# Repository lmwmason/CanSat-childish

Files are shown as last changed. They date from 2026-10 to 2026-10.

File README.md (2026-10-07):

# CanSat-childish







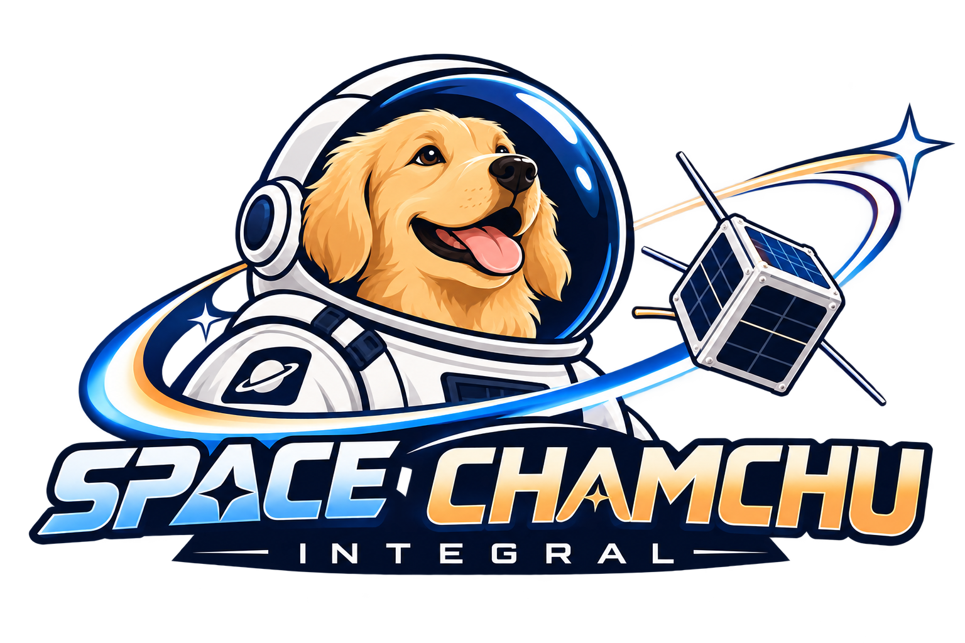
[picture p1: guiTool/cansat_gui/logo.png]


CanSat-childish is the open-source code and hardware for a two-tier CanSat
project by the Space Chamchu team: a **mother CanSat** that is dropped, steadies
itself with a reaction wheel, spins up, opens a door, ejects its wings and
glides back around the drop point, and small **child CanSats** that fall under a
parachute and record the descent. A **ground station** receives the mother's
telemetry over a TBS Crossfire link, shows it live and records it to CSV.

The repository holds every part of the system:

- **Mother firmware** — STM32F410RB. Fuses two IMUs, detects the drop, stabilizes
  and spins the body with a reaction wheel, opens the door, ejects the wings,
  flies the elevons (manual from the radio or automatic with GPS), detects the
  landing, and sends telemetry down the CRSF link.
- **Child firmware** — ATmega328 (Arduino Pro Mini). Reads barometer, IMU and
  humidity sensors, releases a parachute with a servo and logs the whole flight
  to EEPROM so it can be dumped over serial after landing.
- **Ground station** — a PyQt6 desktop app (Mission Planner style) that runs on a
  Raspberry Pi with a Crossfire Micro TX V2, or on a normal PC. Live flight view,
  ground track, CSV recording and the AUX switches of the mother.
- **Simulator** — the flight logic as a hardware-independent C core, run on a
  rigid-body physics engine, with a live 3D viewer.
- **PCB** — the KiCad project of the mother board.

## Mother mission

The mother's mission is a state machine on the STM32. Every number below is a
constant in the source and can be tuned.

1. **Drop detection** — the acceleration magnitude stays between 9.7 and
   9.9 m/s² for 300 ms **and** the AUX1 switch on the radio is on.
2. **2 s later** — the reaction wheel turns on and holds the current heading.
3. **Stable** (yaw rate under 8°/s and yaw error under 10° for 1 s) — the wheel
   spins the body up at full power.
4. **180°/s reached** — the servo opens the door.
5. **5 s at maximum speed**, then the wheel brakes and holds the heading again.
6. **Stable again** — the two wing servos eject the wings.
7. **Elevons** — the AUX2 switch selects manual (sticks) or automatic. Automatic
   mode levels the aircraft and circles around the point where the drop was
   detected (50 m radius) using the GPS.
8. **Landing** — motionless for 3 s (at least 10 s after the drop): the buzzer
   sounds and all LEDs blink.

## Tech stack

- **Mother firmware:** C, STM32 HAL, [STM32CubeMX](https://www.st.com/en/development-tools/stm32cubemx.html) project (`.ioc`) with IAR EWARM project files
- **Sensors on the mother:** MPU6050 + ICM-42688 (I2C), u-blox NEO-6M GPS (I2C / DDC), TBS Crossfire receiver (CRSF, UART)
- **Child firmware:** C++ / Arduino framework with [PlatformIO](https://platformio.org/); BMP280, MPU6050 (on-chip DMP), DHT11
- **Ground station:** Python 3, [PyQt6](https://www.riverbankcomputing.com/software/pyqt/) (Qt Serial Port), [PyInstaller](https://pyinstaller.org/) and AppImage for releases
- **Simulator:** C11, [Open Dynamics Engine](https://www.ode.org/), Python with matplotlib / numpy for the viewer
- **Hardware design:** [KiCad](https://www.kicad.org/)

## Getting started

### Ground station

The easiest way is a build from the
[Releases](https://github.com/lmwmason/CanSat-childish/releases) page:

| File | For |
| ---- | --- |
| `CanSatGroundStation-aarch64.AppImage` | Raspberry Pi 4 / 5, 64-bit OS |
| `CanSatGroundStation-x86_64.AppImage` | Linux PC |
| `CanSatGroundStation-…-windows-x64.zip` | Windows PC |
| `CanSatGroundStation.pyz` + `run-on-pi.sh` | Any Raspberry Pi OS, if the AppImage does not work |

On a Raspberry Pi:

```bash
sudo apt install libfuse2 libxcb-cursor0
chmod +x CanSatGroundStation-aarch64.AppImage
./CanSatGroundStation-aarch64.AppImage
```

To run it from source:

```bash
cd guiTool
python3 -m venv .venv
.venv/bin/pip install -r requirements.txt
.venv/bin/python -m cansat_gui
```

Pick **Demo (synthetic flight)** in the Mother bar to try everything without
hardware. For the real link, choose the serial port and 400000 baud (CRSF). The
wiring between the Raspberry Pi and the Crossfire module is in
[`guiTool/pinmap.md`](./guiTool/pinmap.md). Telemetry is recorded to
`~/CanSat Logs/` (or `guiTool/logs/` when run from source).

Run the tests with `python -m unittest discover -s tests` inside `guiTool`.
To build a release locally:

```bash
pip install -r requirements-build.txt
pyinstaller cansat_gui.spec --noconfirm
tools/make_appimage.sh
```

Pushing a tag named `gui-vX.Y.Z` makes GitHub Actions
([`gui-release.yml`](./.github/workflows/gui-release.yml)) build the AppImages
for aarch64 and x86_64 and the Windows zip, and publish them as a release.

### Mother firmware

1. Open `firmware/motherCansat-Firmware/motherCansat-Firmware.ioc` in
   STM32CubeMX to inspect or regenerate the peripheral setup.
2. Build and flash with your STM32 toolchain (the `EWARM` folder contains the IAR
   project). Keep your own code inside the `USER CODE` blocks of `main.c`.
3. Check the wiring against
   [`firmware/motherCansat-Firmware/pinmap.md`](./firmware/motherCansat-Firmware/pinmap.md).
   Several pins (wheel motor, servos, buzzer, LEDs) are not labeled in the `.ioc`,
   so the pin map is the reference.

The mission constants live in the headers of the modules, for example
`mission.h`, `drop_detect.h`, `landing_detect.h`, `elevon.h` and `nav.h`.

### Child firmware

```bash
cd firmware/childCansat-Firmware
pio run -t upload
pio device monitor -b 115200
```

The serial monitor accepts `s` (status), `d` (dump the flight log as CSV) and
`e` (erase the log).

### Simulator

Needs `gcc`, `make`, the ODE development package (`ode-devel` on Fedora,
`libode-dev` on Debian / Ubuntu) and Python with `matplotlib` and `numpy` for the
viewer.

```bash
cd simulator
./run.sh              # build, then an interactive menu
./run.sh mother       # the mothership simulation
./run.sh child 1      # a child satellite simulation (1 to 3)
./run.sh test         # the headless failsafe test
./run.sh viz          # live 3D telemetry viewer
./run.sh all          # mother + 3 children + viewer together
```

## Project structure

```
firmware/
  childCansat-Firmware/    PlatformIO project of the child CanSat
    src/                   main, boot, mission, sensors, storage (EEPROM log), comm, ui, core, config
    lib/                   bmp280, dht11 and mpu6050 drivers
    pinmap.md              Pin assignments of the child
  motherCansat-Firmware/   STM32CubeMX project of the mother CanSat
    Core/Src/              main.c and the application modules:
                             imu, gps, nav, crsf, drop, mission, reaction_wheel, pid,
                             door, wings, elevon, soft_pwm, wheel_motor, landing, indicator
    pinmap.md              Pin assignments of the mother
guiTool/
  cansat_gui/              The PyQt6 ground station (CRSF decoder, CSV logger, pages)
  tests/                   Frame-format tests against the real firmware output
  tools/                   Packaging scripts (AppImage, .pyz, Raspberry Pi launcher)
  pinmap.md                Wiring Raspberry Pi <-> Crossfire TX module
simulator/
  core/                    Hardware-independent flight logic in C
  sim/                     Mothership and child simulations (physics)
  viz/                     Live 3D viewer (Python)
pcb/
  motherBoard/kicad-pcb/   KiCad project of the mother board
photos/                    Schematic and PCB exports
.github/workflows/         Ground station release build
```

## Status

The mother firmware and the ground station are verified on a PC: the telemetry
frames the firmware produces are decoded correctly by the ground station, and the
mission logic was simulated. They have **not yet been tested end to end on the
real hardware**. The mother's pin assignments are chosen in `pinmap.md`, and the
Crossfire module pins should be checked before powering anything.

## License

Licensed under the [Apache License 2.0](./LICENSE).

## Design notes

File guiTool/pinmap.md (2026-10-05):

# Ground Station Pin Map: Raspberry Pi 4 <-> Crossfire Micro TX V2

Wiring for the ground station (`guiTool`). The Raspberry Pi acts as the transmitter: it sends RC frames
(AUX1 / AUX2) to the Crossfire module and reads the telemetry the module returns.

The mother CanSat side is in the firmware `pinmap.md`. This file only covers the ground side.

**Read the "Verify before powering" section first.** The module's JR-bay pin numbers come from community
documentation, not from a TBS pinout drawing for the Micro TX V2.

## What the module is

- The Crossfire Micro TX V2 is a JR-bay module (it plugs into the external module bay of a radio).
- Input voltage: 6.0 - 13 V.
- Its USB-C port is documented for power and firmware update (TBS Agent). It is **not** documented as a
  CRSF serial port, so the Pi talks to the module through the JR-bay signal pin, not through USB.

## JR module bay pins (standard, top to bottom)

| JR pin | Name | Use here |
|---|---|---|
| 1 | PPM | not connected |
| 2 | +6V (regulated, output of a radio) | not connected (see "Verify") |
| 3 | +BAT (raw battery voltage) | module power, 6 - 13 V |
| 4 | GND | ground (shared with the Pi) |
| 5 | ANT / S.Port | **CRSF data**, single-wire half-duplex |

## Wiring

| From | To | Notes |
|---|----|---|
| Pi pin 8 (GPIO14, TXD0) | diode anode (Schottky, e.g. BAT54 / 1N5819) | transmit path |
| diode cathode | JR pin 5 (CRSF data) | the diode lets the Pi pull the line low but never drive it high |
| JR pin 5 (CRSF data) | Pi pin 10 (GPIO15, RXD0) | receive path, connected directly |
| Pi pin 1 (3V3) | 4.7 kohm resistor -> JR pin 5 | pull-up so the line idles high |
| Pi pin 6 (GND) | JR pin 4 (GND) | common ground, required |
| battery / supply (6 - 13 V) | JR pin 3 (+BAT) | module power. Share its ground with JR pin 4 |

```
 Pi TXD (pin 8) ----|>|----+---- JR pin 5 (CRSF data, half-duplex)
                           |
 Pi RXD (pin 10) ----------+
                           |
 Pi 3V3 (pin 1) --[4.7k]---+

 Pi GND (pin 6) ------------------ JR pin 4 (GND) ---- supply GND
                                   JR pin 3 (+BAT) --- supply + (6 - 13 V)
```

- Everything on the Pi side is 3.3 V logic. Do not connect a 5 V signal to the Pi.
- The Pi receives its own transmitted bytes (half-duplex echo). The software ignores them.
- The diode + pull-up circuit is a standard way to run a single-wire UART from a push-pull Pi pin. It is
  a starting design for 400 kbaud, so check the waveform with a scope or logic analyser.
- Size the supply for the module's transmit current (check the TBS specification). Do not power the module
  from the Pi's 5 V pins.

## Raspberry Pi setup

1. In `/boot/firmware/config.txt` (older images: `/boot/config.txt`) add:
   ```
   enable_uart=1
   dtoverlay=disable-bt
   ```
   This gives the full PL011 UART (`/dev/serial0` -> `ttyAMA0`) on GPIO14/15. The mini-UART is not suitable
   for a precise 400 kbaud.
2. `sudo raspi-config` -> Interface Options -> Serial Port -> login shell over serial: **No**, serial
   hardware: **Yes**. Reboot.
3. `sudo usermod -aG dialout $USER`, then log out and in.
4. Check the baud rate can be set: `stty -F /dev/serial0 400000`.
5. Make a new virtual environment on the Pi (the `.venv` in this repo was built on x86 and does not work on
   the Pi):
   ```
   cd guiTool
   python3 -m venv .venv
   .venv/bin/pip install -r requirements.txt
   .venv/bin/python -m cansat_gui
   ```
   Use a 64-bit Raspberry Pi OS so a PyQt6 wheel is available.
6. In the Mother connection bar choose `serial0` and **400000 baud** (the default).

## Baud rates

| Link | Baud |
|---|---|
| Pi <-> Crossfire TX module (JR bay) | 400000 (default in the app) |
| Crossfire receiver <-> mother CanSat (firmware USART6) | 420000 (the receiver speaks about 416666; the 0.8 % difference is within UART tolerance) |

The app treats 400000, 416666 and 420000 as CRSF. Any other baud rate is the old text-line protocol.

## Verify before powering

These were **not** confirmed from a TBS document for the Micro TX V2:

1. The physical order and orientation of the module's JR pins. Check with a multimeter (continuity to the
   radio-bay drawing, or the supply pins) before applying power. A wrong connection on +BAT / GND can
   destroy the module.
2. That the CRSF data pin is JR pin 5. This is the common convention (it is the S.Port / antenna pin), but
   confirm it for this module.
3. Whether the module needs the +6V pin (JR pin 2) or accepts power on +BAT alone.
4. Whether the module needs the handset to hold the data line high (the pull-up above covers this) and
   that its logic level is 3.3 V.
5. The handset <-> module baud rate (400000 is the usual default; try 416666 / 420000 if no frames arrive).

If no telemetry shows up, the Actions tab shows the CRSF frame and CRC error counters. Zero frames means a
wiring, baud or half-duplex problem. Frames with CRC errors usually mean a wrong baud rate or a noisy line.

## Sources

- [TBS Crossfire Micro TX quick-start guide](https://www.team-blacksheep.com/media/files/tbs-crossfire-micro-tx-quickstart.pdf): JR form factor, CRSF output.
- [Transmitter external module pinout (Stavros' Notes)](https://notes.stavros.io/drone-stuff/transmitter-external-module-pinout/): JR bay pins 1 - 5.
- [ExpressLRS radio preparation](https://www.expresslrs.org/quick-start/transmitters/tx-prep/): modules need VBAT, GND and S.Port/data; 400000 / 921000 / 1.87M baud options.
- [Oscar Liang: TBS Crossfire Micro TX V2](https://oscarliang.com/tbs-crossfire-micro-tx-v2/): 6 - 13 V input, USB-C for power and firmware.

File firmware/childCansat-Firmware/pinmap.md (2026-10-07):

# Child CanSat Pin Map (Arduino Pro Mini, ATmega328P, 5 V / 16 MHz)

Every pin below is taken from the firmware (`src/config/config.h` and the code that uses it), so this file
matches what the program does. Change a pin in `config.h` and update this file as well.

The PlatformIO environment is `pro16MHzatmega328` (Pro Mini **5 V / 16 MHz**). If you build the circuit
around the 3.3 V / 8 MHz Pro Mini, the environment and the timings have to be changed too.

## Pins used by the firmware

| Arduino pin | Function | Mode | Notes | Code location |
|---|---|---|---|---|
| D2 | DHT11 data (temperature, humidity) | input with pull-up, driven as output while reading | `dhtPin` | `lib/dht11/dht11.cpp` |
| D3 | Deploy sensor | input with pull-up | **LOW = still stored in the mother, HIGH = released** (see below) | `src/mission/mission.cpp` |
| D4 | Parachute servo signal | Servo library | locked 0 deg, released 90 deg | `src/mission/boot.cpp` |
| D5 | Buzzer | `tone()` at 2700 Hz | a passive piezo buzzer is the intended type | `src/ui/indicator.cpp` |
| D6 | Yellow LED (**the only LED fitted**) | PWM with `analogWrite()`, level `yellowLedLevel` (25 of 255) | no series resistor, see the LED note below | `src/ui/indicator.cpp`, `src/config/config.h` |
| D7 | Red LED | output, high = on | not fitted in this build, the firmware still drives it | `src/ui/indicator.cpp` |
| D8 | Blue LED | output, high = on | not fitted in this build, the firmware still drives it | `src/ui/indicator.cpp` |
| A4 | I2C SDA | Wire, 400 kHz | BMP280 (0x76), MPU6050 (0x68) | `lib/bmp280`, `lib/mpu6050` |
| A5 | I2C SCL | Wire, 400 kHz | same bus | same as above |
| D0 (RX) / D1 (TX) | Serial, 115200 baud | UART | flight log commands and dump (`s`, `d`, `e`), also used for uploading | `src/comm/serial_cmd.cpp` |

I2C addresses: BMP280 `SDO` pin low = 0x76, MPU6050 `AD0` pin low = 0x68. They do not collide.

Not used by the firmware: D9 - D13, A0 - A3, A6, A7. D13 is the onboard LED.

## Deploy sensor (D3)

The pin has the internal pull-up enabled, so it reads HIGH when nothing is connected.

- While the child is stored in the mother, a contact (a micro switch, or a reed switch with a magnet)
  must connect **D3 to GND**.
- When the child is released, the contact opens and D3 goes HIGH. If it stays HIGH for 1.5 s while the
  state is ARMED, the firmware starts the descent (parachute release, logging).
- With nothing connected to D3 the child will start its descent 1.5 s after it is armed.
- After a reset in mid-flight the firmware checks D3 for 100 ms. If the last log record is DESCENT and the
  pin is HIGH, it resumes the flight instead of starting over.

## Indicators

| LED | ARMED | DESCENT | LANDED |
|-----|---|---|---|
| Yellow | on once the log has records, fast blink when the log is full | short flash on every log write, fast blink when full | cycles with red and blue (900 ms) |
| Red | barometer or IMU fault | barometer or IMU fault | cycles with yellow and blue |
| Blue | short pulse every second | steady on | cycles with yellow and red |

At power-up the yellow LED is on, then blinks during the 9 s warm-up.

| Buzzer pattern | Meaning |
|---|---|
| one 60 ms beep | start-up |
| two short beeps | sensors ready |
| three long beeps | sensor fault (repeats every 5 s while armed) |
| one 700 ms beep | descent started, parachute released |
| three beeps, 2 s pause, repeating | landed, find-me beacon |

## Serial and upload

The Pro Mini has no USB port. Connect a USB-serial adapter (3.3 V or 5 V to match the board) to the 6-pin header
(`GND`, `CTS`, `VCC`, `TXO`, `RXI`, `DTR`). The same connection is used for uploading and for the log dump.
Opening the serial port pulses `DTR` and resets the board. The firmware resumes a flight in progress after
such a reset (see above). The ground station's Data page works at 115200 baud.

## Electrical notes for the circuit

- **Supply:** the firmware does not measure the battery. Power the board through `RAW` (regulated on board)
  or `VCC` with a regulated 5 V, and share one GND with every module.
- **Logic level:** the board runs at 5 V. Check that the BMP280, MPU6050 and DHT11 breakout boards accept 5 V on
  the I2C and data lines. Many BMP280 boards are 3.3 V only, so use one with a regulator and level shifting, or
  a level shifter.
- **I2C pull-ups:** one bus with two devices. Breakout boards often have their own 4.7 kohm pull-ups. Do not stack
  so many that the combined value gets too low.
- **Servo:** power the parachute servo from a supply that can handle its stall current, with its GND tied to the
  board GND. Put about 1 kohm in series with the signal line.
- **Buzzer:** one ATmega pin should not source more than about 20 mA. Use a transistor if the buzzer needs more
  current.
- **Yellow LED without a resistor (D6):** the firmware dims it with PWM (`yellowLedLevel`, about 10 %), which keeps the
  *average* current near a normal LED current. PWM does not limit the current while the pin is on. A 5 V pin
  can push far more than 20 mA into a bare LED for those short pulses, which can shorten the life of the LED and
  of the pin. If there is any room, solder a 330 ohm resistor directly onto one LED leg. That takes no extra board
  space and makes the LED safe. Keep `yellowLedLevel` low, and leave D7 / D8 unconnected or use resistors.
- **DHT11:** needs a pull-up on the data line (4.7 - 10 kohm to VCC). Most modules already have one. Wait at least
  1 s after power-up before the first reading (the firmware does).
- **Timers:** the Servo library uses Timer1 (PWM on D9 / D10 is lost) and `tone()` uses Timer2 (PWM on D3 / D11).
  None of those pins is used for PWM here.

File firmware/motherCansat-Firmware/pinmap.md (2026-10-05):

# Mother CanSat Pin Map (STM32F410RB)

This is the pin map the firmware uses and the reference for the circuit design.
If you change one, update the file listed under "Code location" as well.

## Communication / sensors

| Pin | Function | Setting | Connected to | Code location |
|-----|---|---|---|---|
| PB6 | I2C1 SCL | 100 kHz | MPU6050 (0x68), ICM-42688 (0x69), NEO-6M GPS (0x42) | `imu/imu.h`, `gps/gps.h` |
| PB7 | I2C1 SDA | 100 kHz | same as above | |
| PC6 | USART6 TX | 420000 baud, 8N1 | CRSF receiver (Crossfire Nano RX) | `crsf/crsf.c` |
| PC7 | USART6 RX | 420000 baud, interrupt RX | same as above | |
| PA2 | USART2 TX | 115200 baud | Debug output (ST-Link VCP) | `main.c` |
| PA3 | USART2 RX | 115200 baud | same as above | |

- I2C address conflict avoided: MPU6050 has AD0 = low (0x68), ICM-42688 has AD0 = high (0x69).
- The NEO-6M breakout must expose its I2C (DDC) pins. Many boards only break out UART.

## Actuators

| Pin | Function | Timer / method | Code location |
|-----|---|---|---|
| PA8 | Reaction wheel motor, forward PWM **(chosen)** | TIM1 CH1, 20 kHz | `wheel_motor/wheel_motor.h` |
| PA9 | Reaction wheel motor, reverse PWM **(chosen)** | TIM1 CH2, 20 kHz | same as above |
| PA0 | Door servo **(chosen)** | TIM5 CH1, 50 Hz, 1 us tick | `door/door.h` |
| PA1 | Wing ejection servos (2, signal wired in parallel) **(chosen)** | TIM5 CH2, 50 Hz | `wings/wings.h` |
| PC8 | Left elevon servo | Software PWM (TIM5 interrupt) | `soft_pwm/soft_pwm.c` |
| PC9 | Right elevon servo | Software PWM (TIM5 interrupt) | same as above |

Servo pulse widths (us):

| Servo | Default | Active |
|---|---|---|
| Door | 1000 (closed) | 2000 (open) |
| Wings | 1000 (locked) | 2000 (ejected) |
| Elevons | 1500 (neutral) | neutral +/- 400 |

## Indicators

| Pin | Function | Code location |
|-----|---|---|
| PA4 | Buzzer **(chosen)**, active buzzer (high = sound) | `indicator/indicator.h` |
| PA5 | LD2 (green onboard LED): on while a drop is detected, blinks after landing | same as above |
| PB12 | LED **(chosen)**: blinks after landing | same as above |
| PB13 | LED **(chosen)** | same as above |
| PB14 | LED **(chosen)** | same as above |
| PB15 | LED **(chosen)** | same as above |

## Controller (CRSF) channels

| Channel | Use | Code location |
|---|-----|---|
| CH1 | Manual mode roll (aileron stick) | `elevon/elevon.h` |
| CH2 | Manual mode pitch (elevator stick) | same as above |
| CH5 (AUX1) | Drop detection switch (drop condition, mission start/reset) | `crsf/crsf.h` |
| CH6 (AUX2) | Elevon mode: on = manual, off = automatic (automatic if the link is lost) | `elevon/elevon.h` |

## Configured but not used by the code

| Pin | CubeMX setting | Note |
|-----|---|---|
| PC12 | TIM11 CH1 (50 Hz, 1 us tick) | Looks like a servo output. Could be used to split the two wing servos |
| PA10 | TIM1 CH3 (20 kHz) | Unused |
| PC0-PC4 | GPIO output | Unused |
| PC5 | Analog | Unused |
| PA12 | GPIO input | Unused |
| PC13 | B1 (blue button) | Unused |

## Reserved pins (do not use)

| Pin | Use |
|-----|-----|
| PA13 / PA14 / PB3 | SWD (SWDIO / SWCLK / SWO) |
| PC14 / PC15 | 32 kHz crystal |
| PH0 / PH1 | External crystal (HSE) |

## Timer summary

| Timer | Rate | Use |
|---|---|-----|
| TIM1 | 20 kHz (ARR 4199, 84 MHz) | Wheel motor PWM |
| TIM5 | 50 Hz (PSC 83, ARR 19999) | Servo PWM (CH1, CH2) + elevon software PWM (CH3/CH4 compare interrupts, no pin output) |
| TIM11 | 50 Hz (PSC 83, ARR 19999) | CH1 configured (PC12), not used by the code |

## Electrical notes for the circuit

- **Servo power:** run the servos (door, wings, 2 elevons) from a separate 5 V supply (BEC) that can handle their stall current. Share GND with the MCU. Do not power them from the 3.3 V rail or the ST-Link 5 V.
- **Servo signal:** the 3.3 V PWM from the MCU works for most servos. Add about 1 kohm in series with each signal line.
- **Wing servos:** the 2 wing servos share PA1, so wire both signal lines to it (each with its own series resistor). The code drives them together.
- **Wheel motor driver:** use a dual-PWM H-bridge (for example DRV8833 or similar) with PA8 on IN1 and PA9 on IN2. Power the motor from the battery rail and add bulk capacitance close to the driver. A reaction wheel draws high current when braking.
- **Buzzer (PA4):** a GPIO can only source about 25 mA. Use an NPN transistor or logic MOSFET if the buzzer needs more, with a flyback diode if it is a magnetic type. It must be an active buzzer.
- **LEDs (PA5, PB12-PB15):** add a series resistor to each (330 ohm to 1 kohm). PA5 is already the onboard LD2.
- **I2C (PB6/PB7):** one bus with 3 devices. Use 4.7 kohm pull-ups to 3.3 V, and check that the breakout boards do not already add their own (several in parallel lowers the resistance too far).
- **Voltage levels:** MPU6050, ICM-42688 and NEO-6M must all be on the 3.3 V bus. Check that your breakout boards do not level-shift to 5 V.
- **GPS:** connect the NEO-6M DDC pins (SDA/SCL), not only TX/RX. Give it a clear view of the sky.
- **CRSF receiver (PC6/PC7):** wire the receiver TX to PC7 (MCU RX) and the receiver RX to PC6 (MCU TX). Power it from 5 V.
- **MCU I/O:** all of the pins above are 3.3 V logic. PA13, PA14 and PB3 stay free for the SWD connector.

## Notes

- `TIM5_IRQHandler` (in `soft_pwm.c`) and `USART6_IRQHandler` (in `crsf.c`) are defined directly in the code. If you enable those interrupts in CubeMX, you will get duplicate definitions, so delete one of each pair.

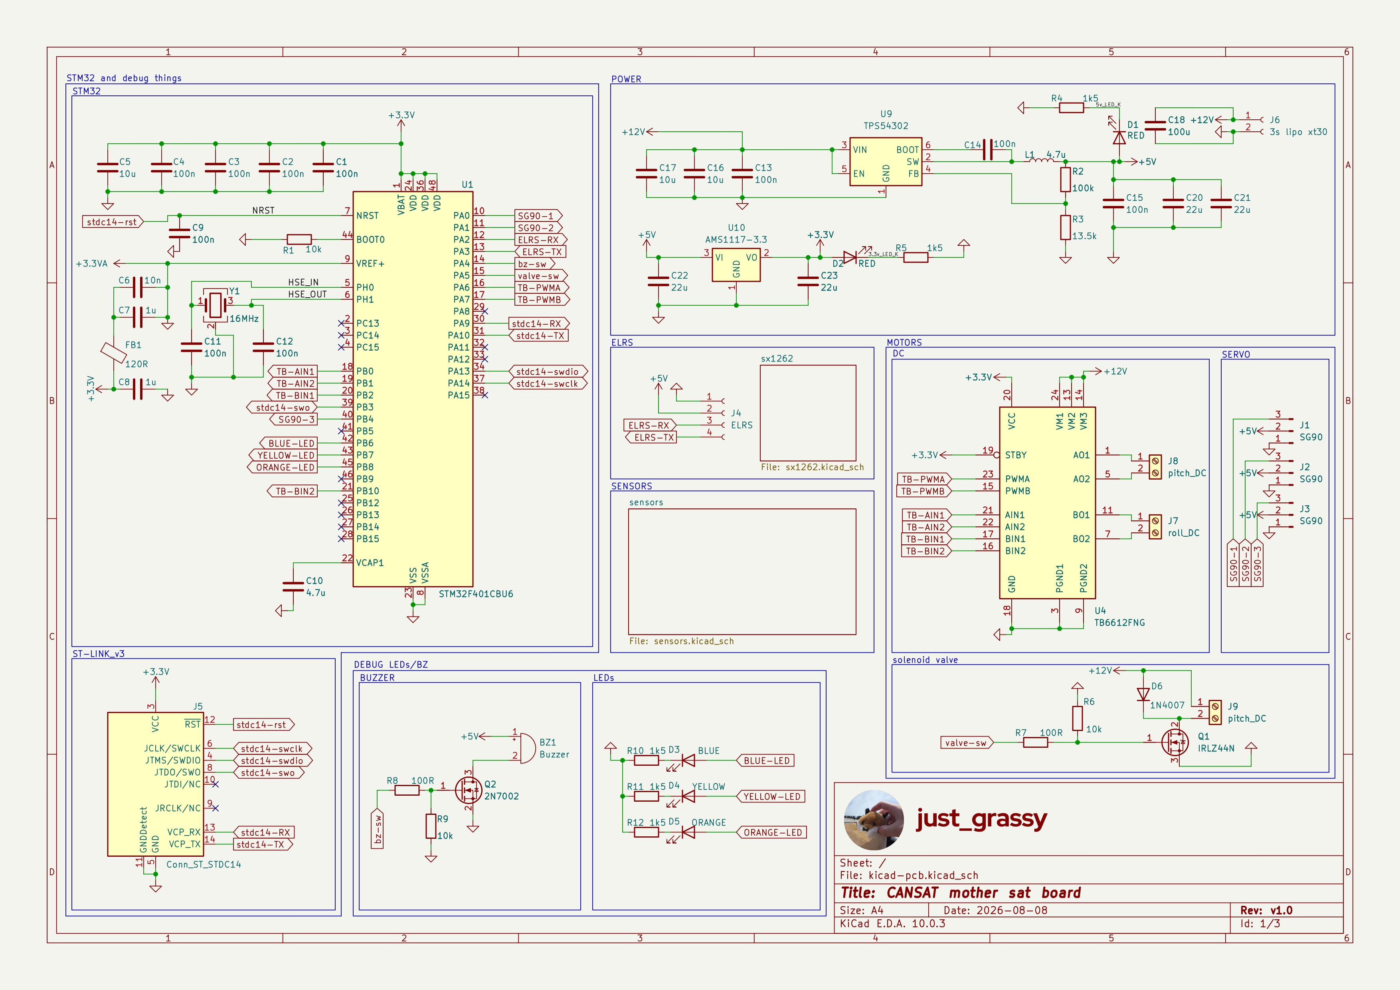
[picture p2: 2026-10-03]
photos/08.08/kicad-pcb_page-0001.jpg

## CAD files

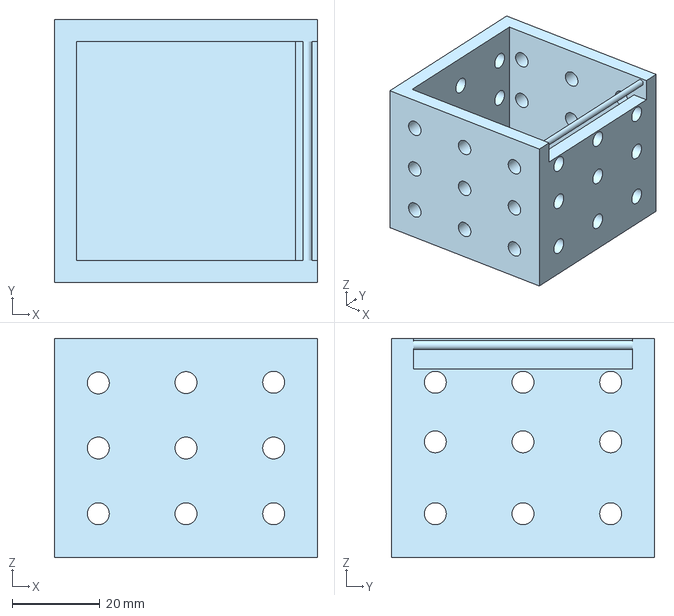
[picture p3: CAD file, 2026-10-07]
3d-model/child-cansat/child-cansat-body.3mf
60.0 x 60.0 x 50.0 mm

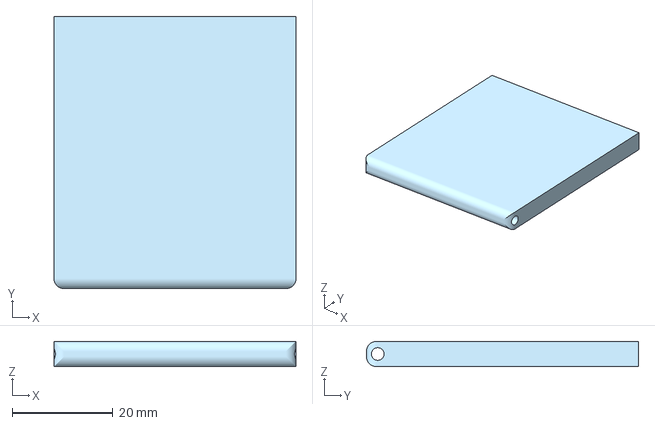
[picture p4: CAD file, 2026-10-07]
3d-model/child-cansat/child-cansat-cover.3mf
48.0 x 54.0 x 5.00 mm

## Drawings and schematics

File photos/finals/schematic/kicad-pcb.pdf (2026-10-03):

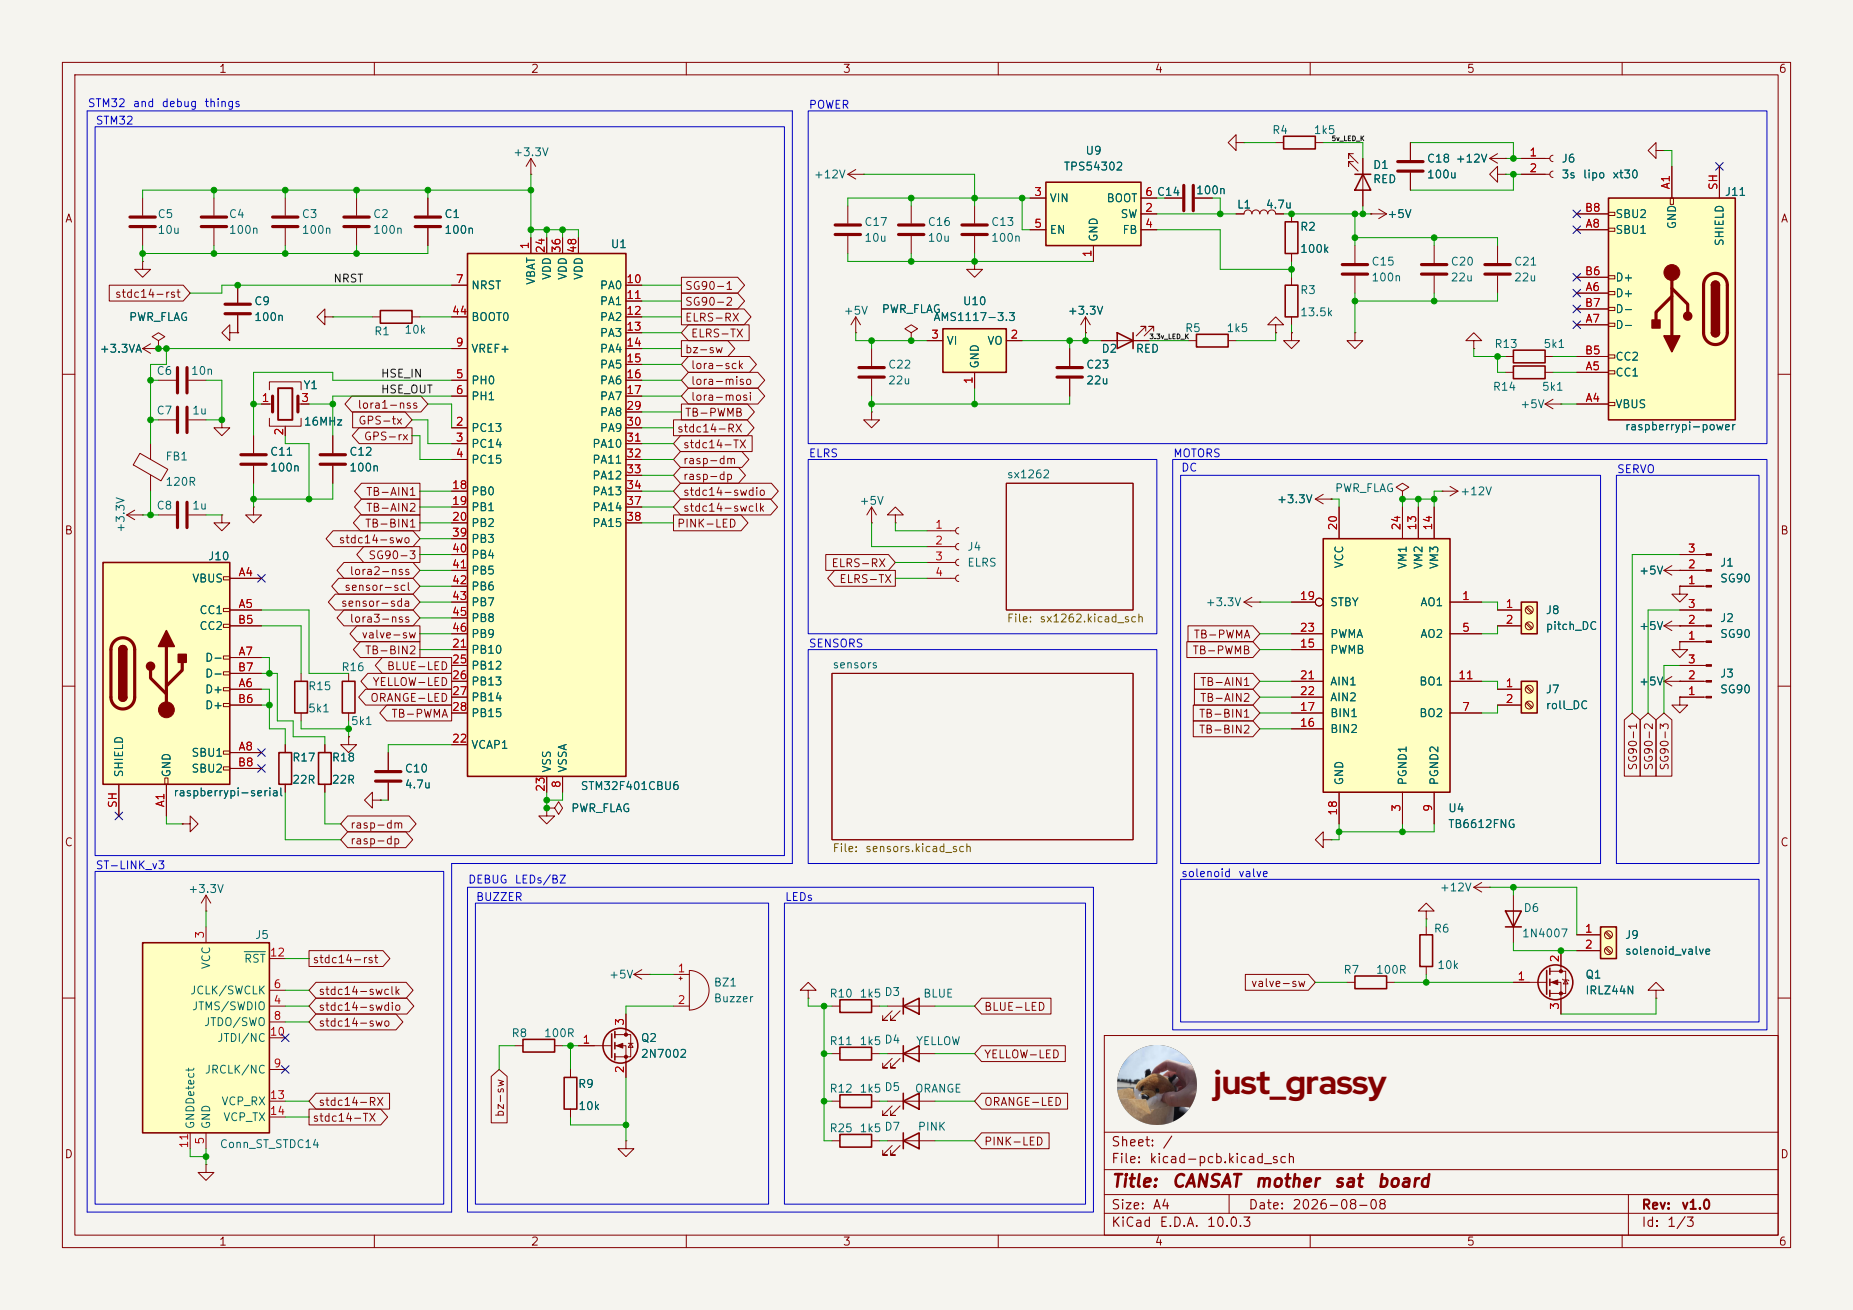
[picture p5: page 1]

lora-mosi TB-PWMB ORANGE-LED

TB-PWMA BLUE-LED
TB-PWMB ORANGE-LED

DEBUG LEDs/BZ BUZZER

Sheet: /
File: kicad-pcb.kicad_sch
Title: CANSAT mother sat board

Size: A4 | Rev: v1.0
KiCad E.D.A. 10.0.3 | Id: 1/3

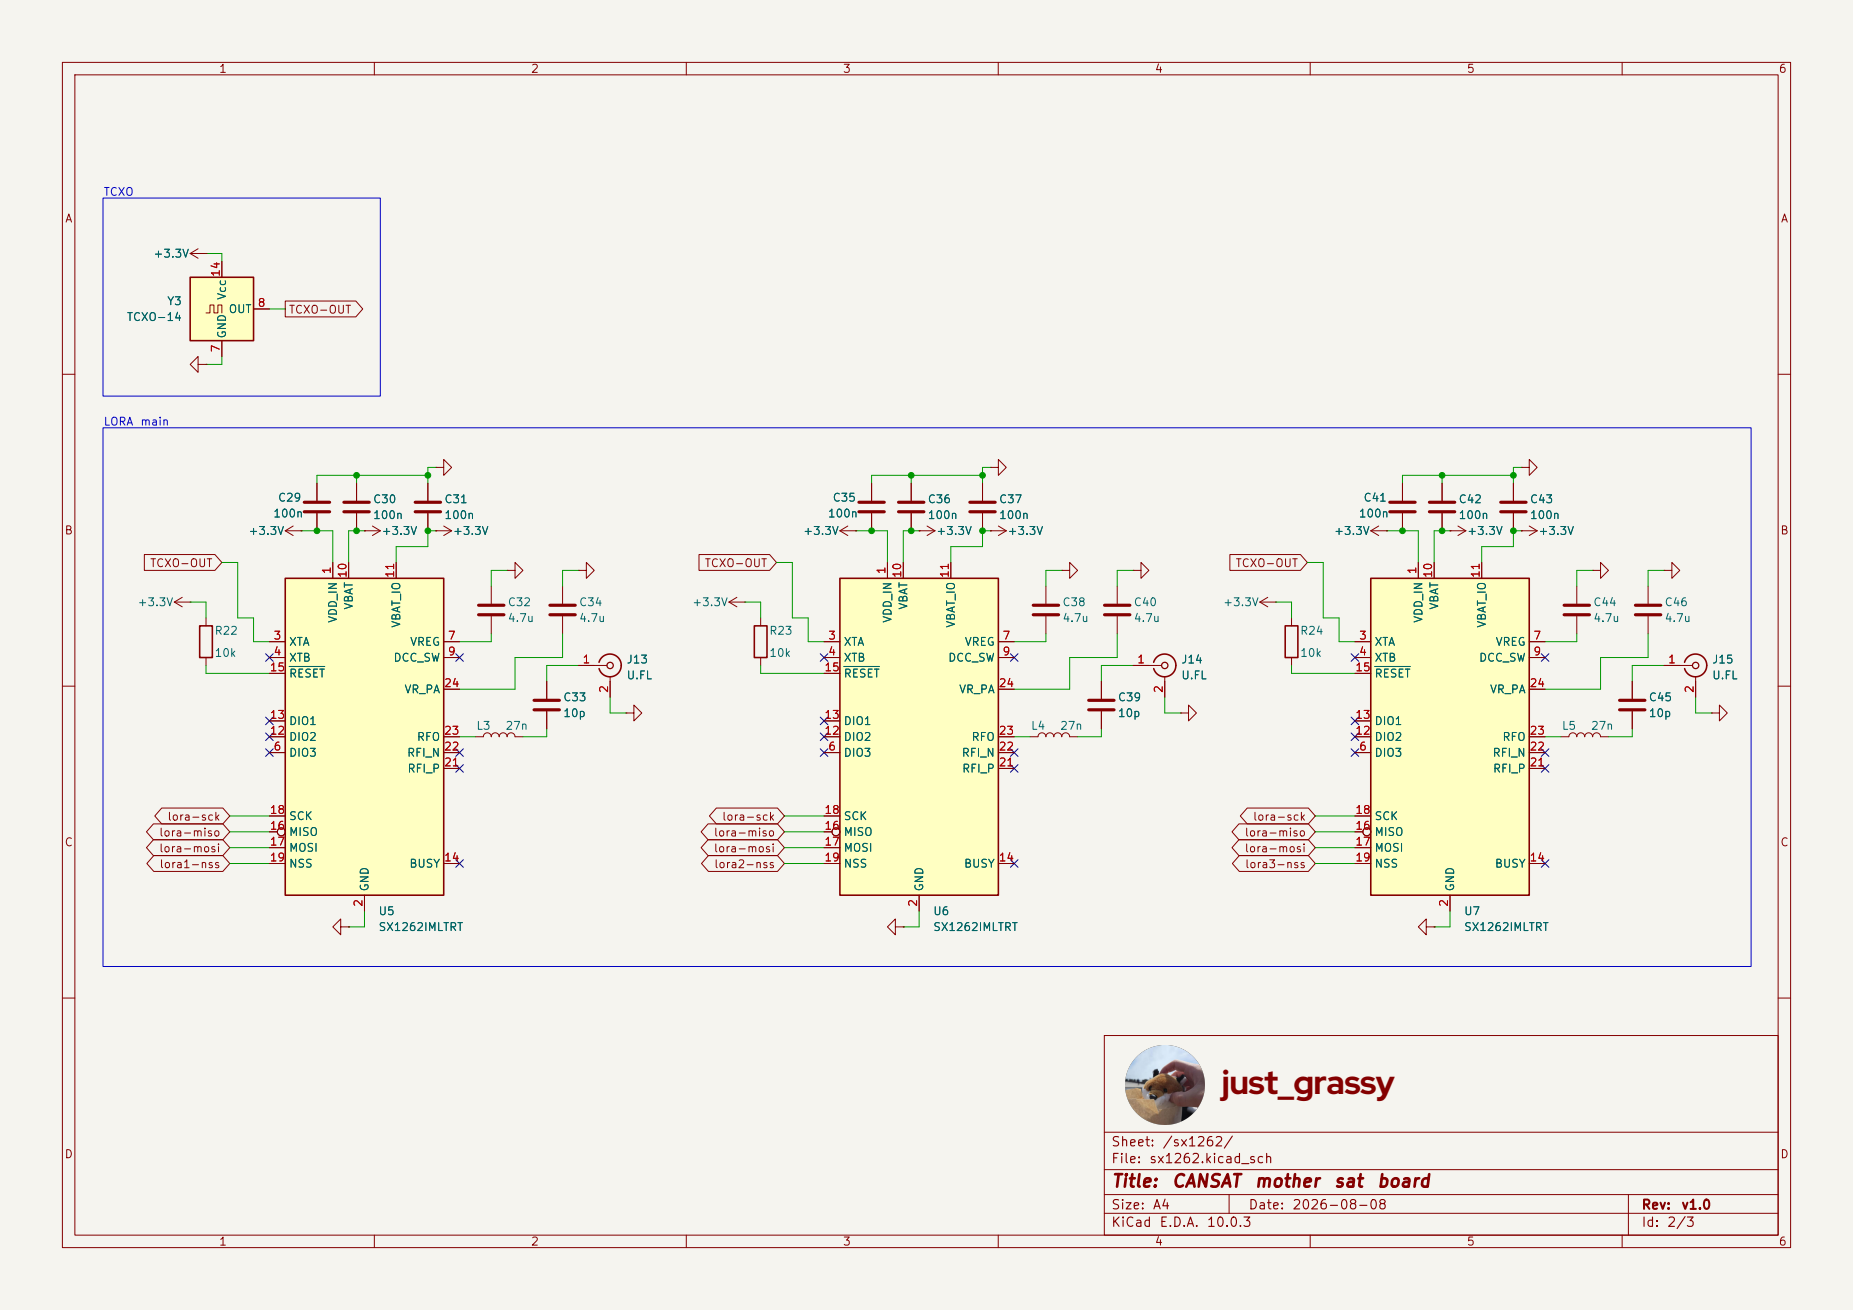
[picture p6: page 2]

lora-sck
lora-mosi lora-miso
lora-mosi lora1-nss

Sheet: /sx1262/
File: sx1262.kicad_sch
Title: CANSAT mother sat board

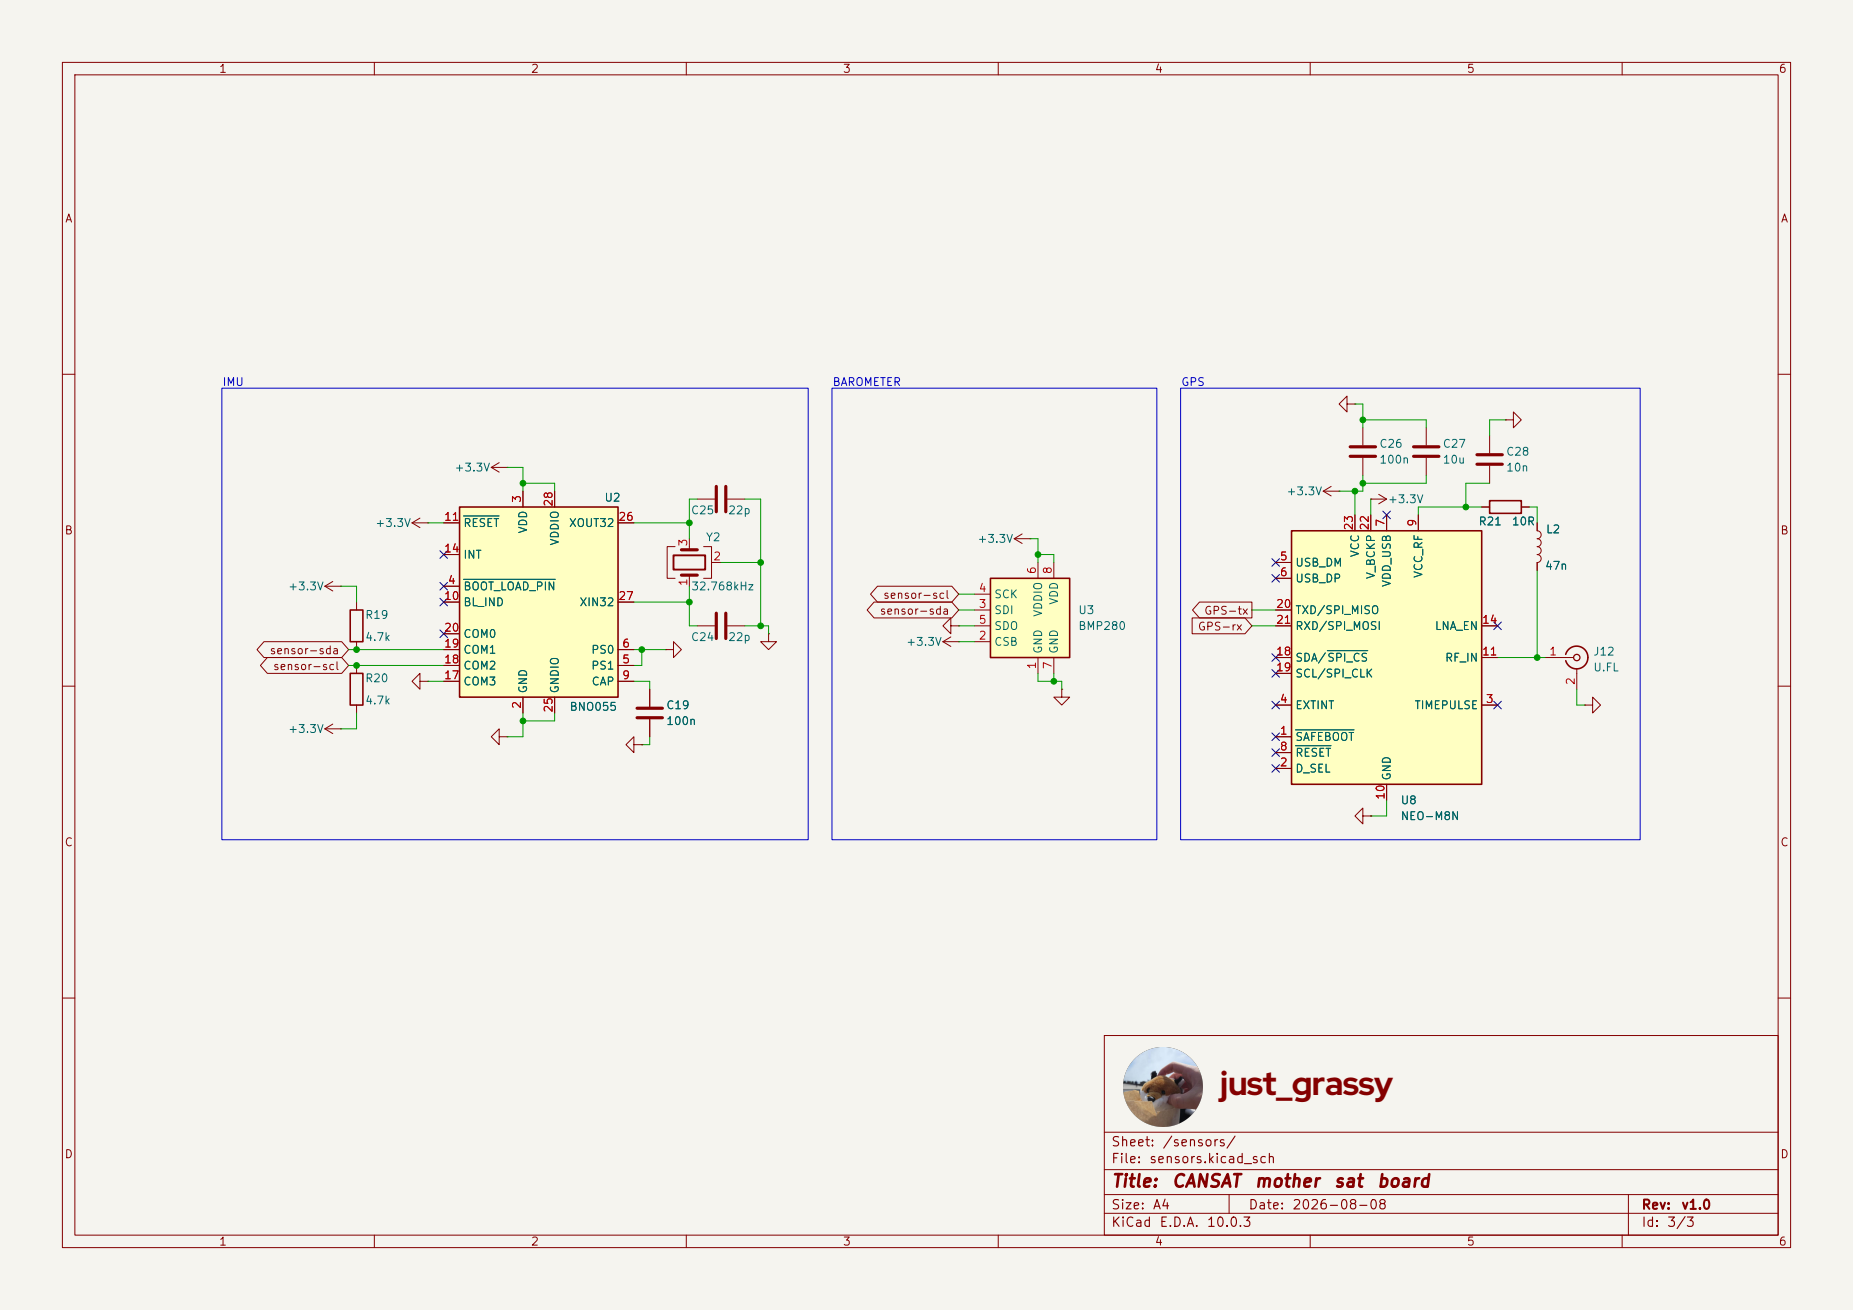
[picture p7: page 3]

Sheet: /sensors/
File: sensors.kicad_sch
Title: CANSAT mother sat board

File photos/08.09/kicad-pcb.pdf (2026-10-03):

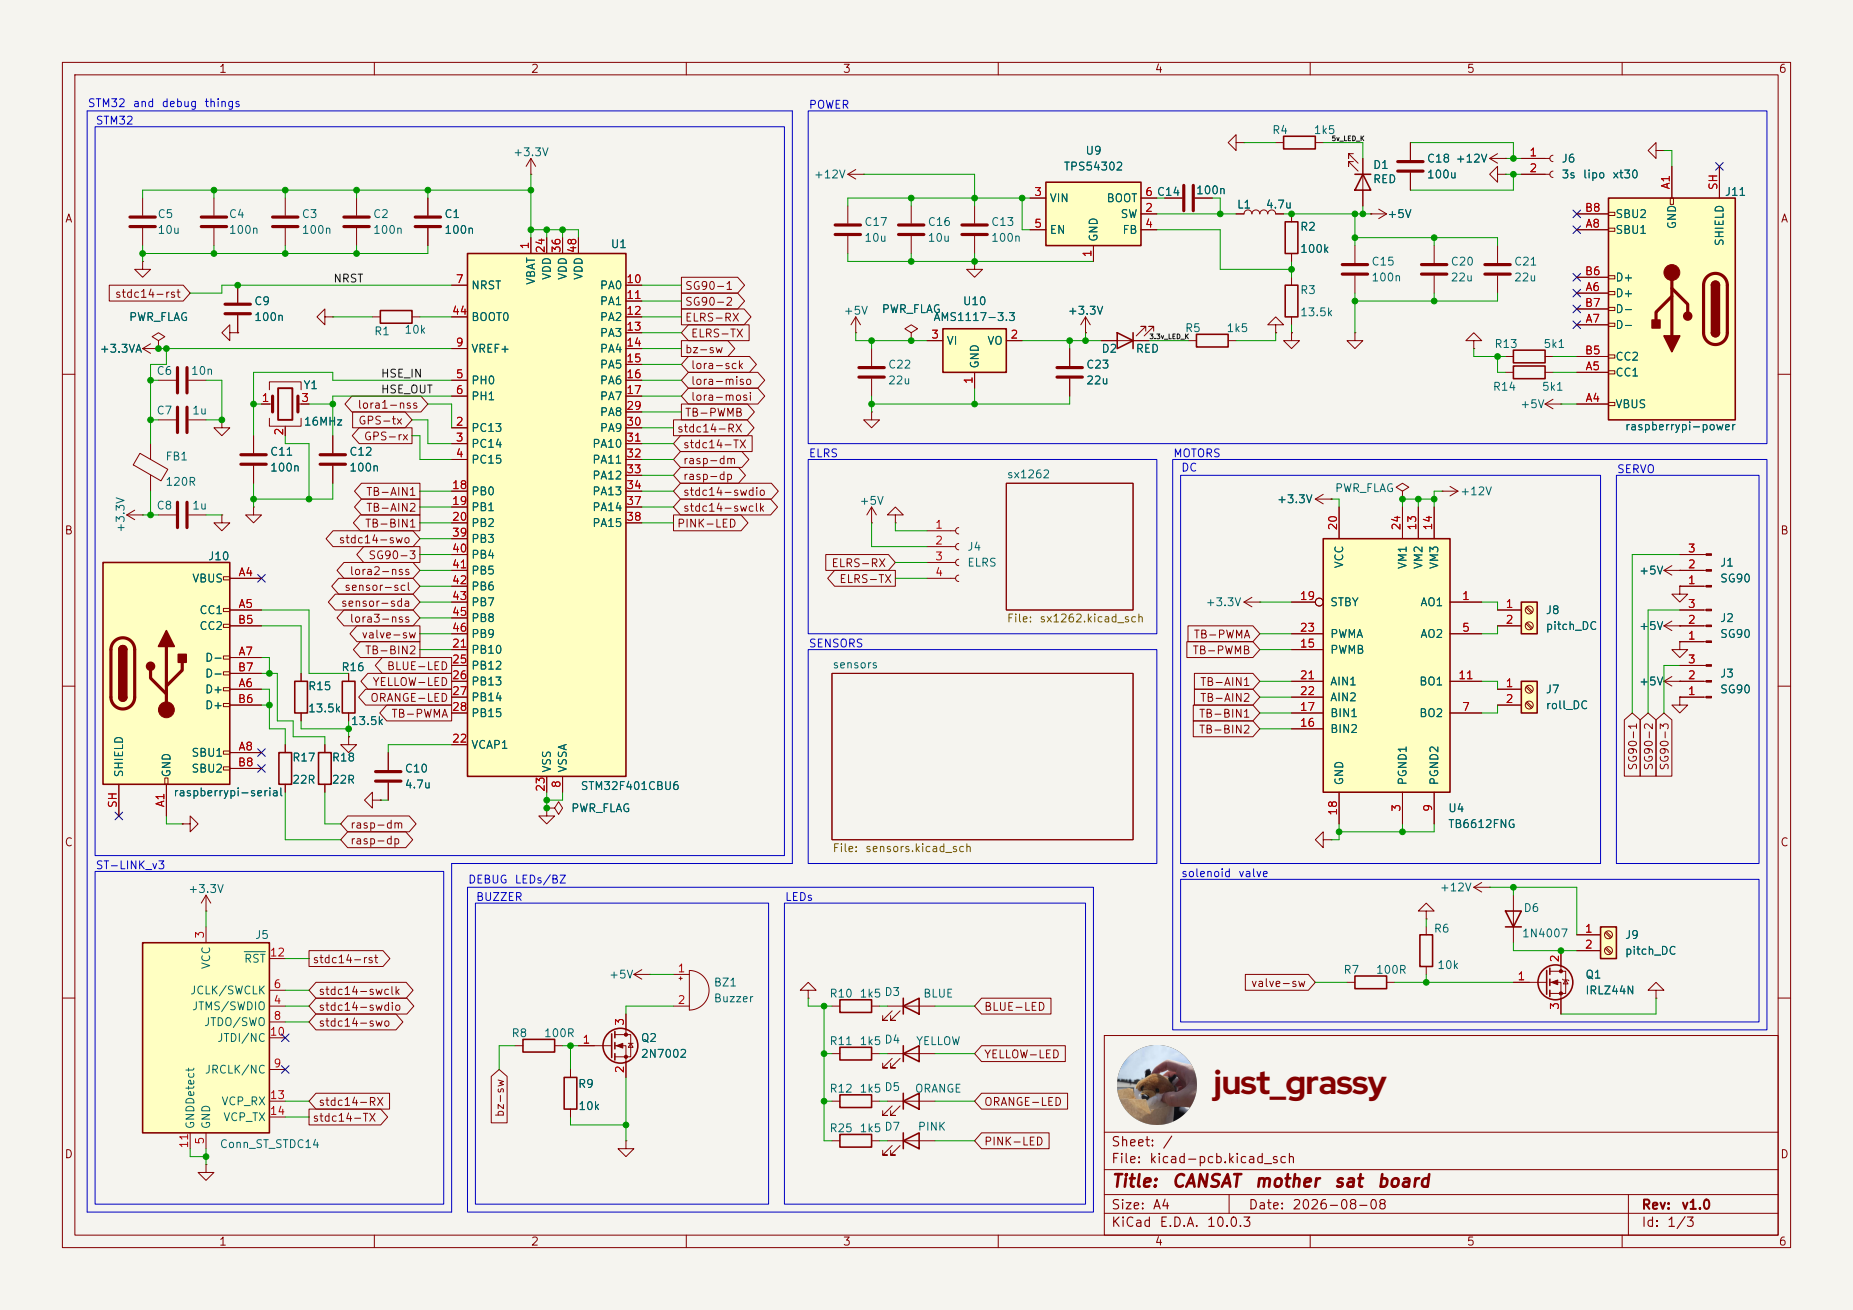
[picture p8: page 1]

ELRS-TX
lora-mosi bz-sw
lora-miso

ELRS DEBUG LEDs/BZ

valve-sw
TB-BIN2
TB-PWMA BLUE-LED ORANGE-LED
YELLOW-LED

YELLOW-LED ORANGE-LED

Sheet: /
File: kicad-pcb.kicad_sch
Title: CANSAT mother sat board

Size: A4 | Rev: v1.0
KiCad E.D.A. 10.0.3 | Id: 1/3

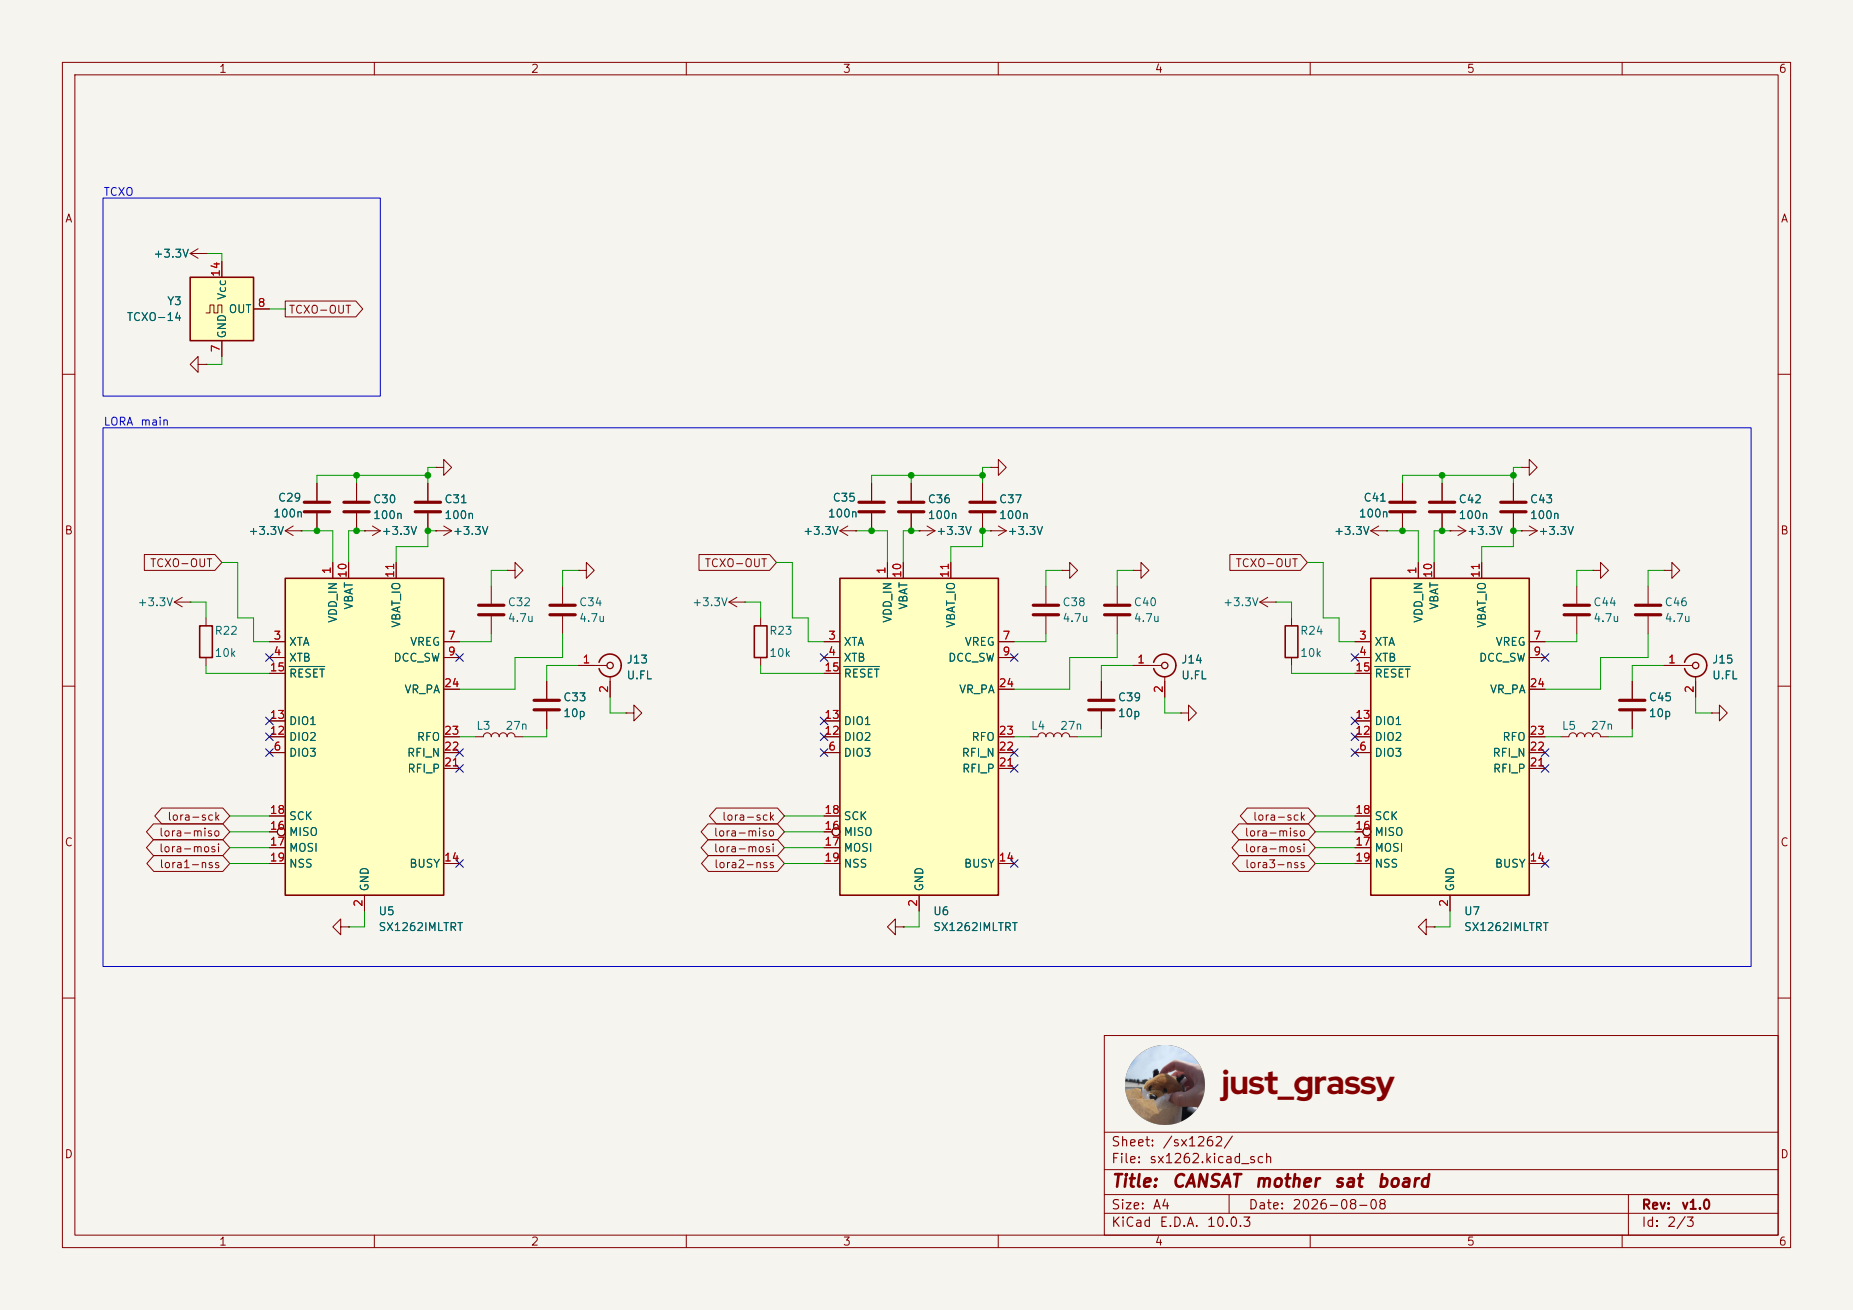
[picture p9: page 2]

lora-mosi TCXO-OUT

File: sx1262.kicad_sch
Title: CANSAT mother sat board

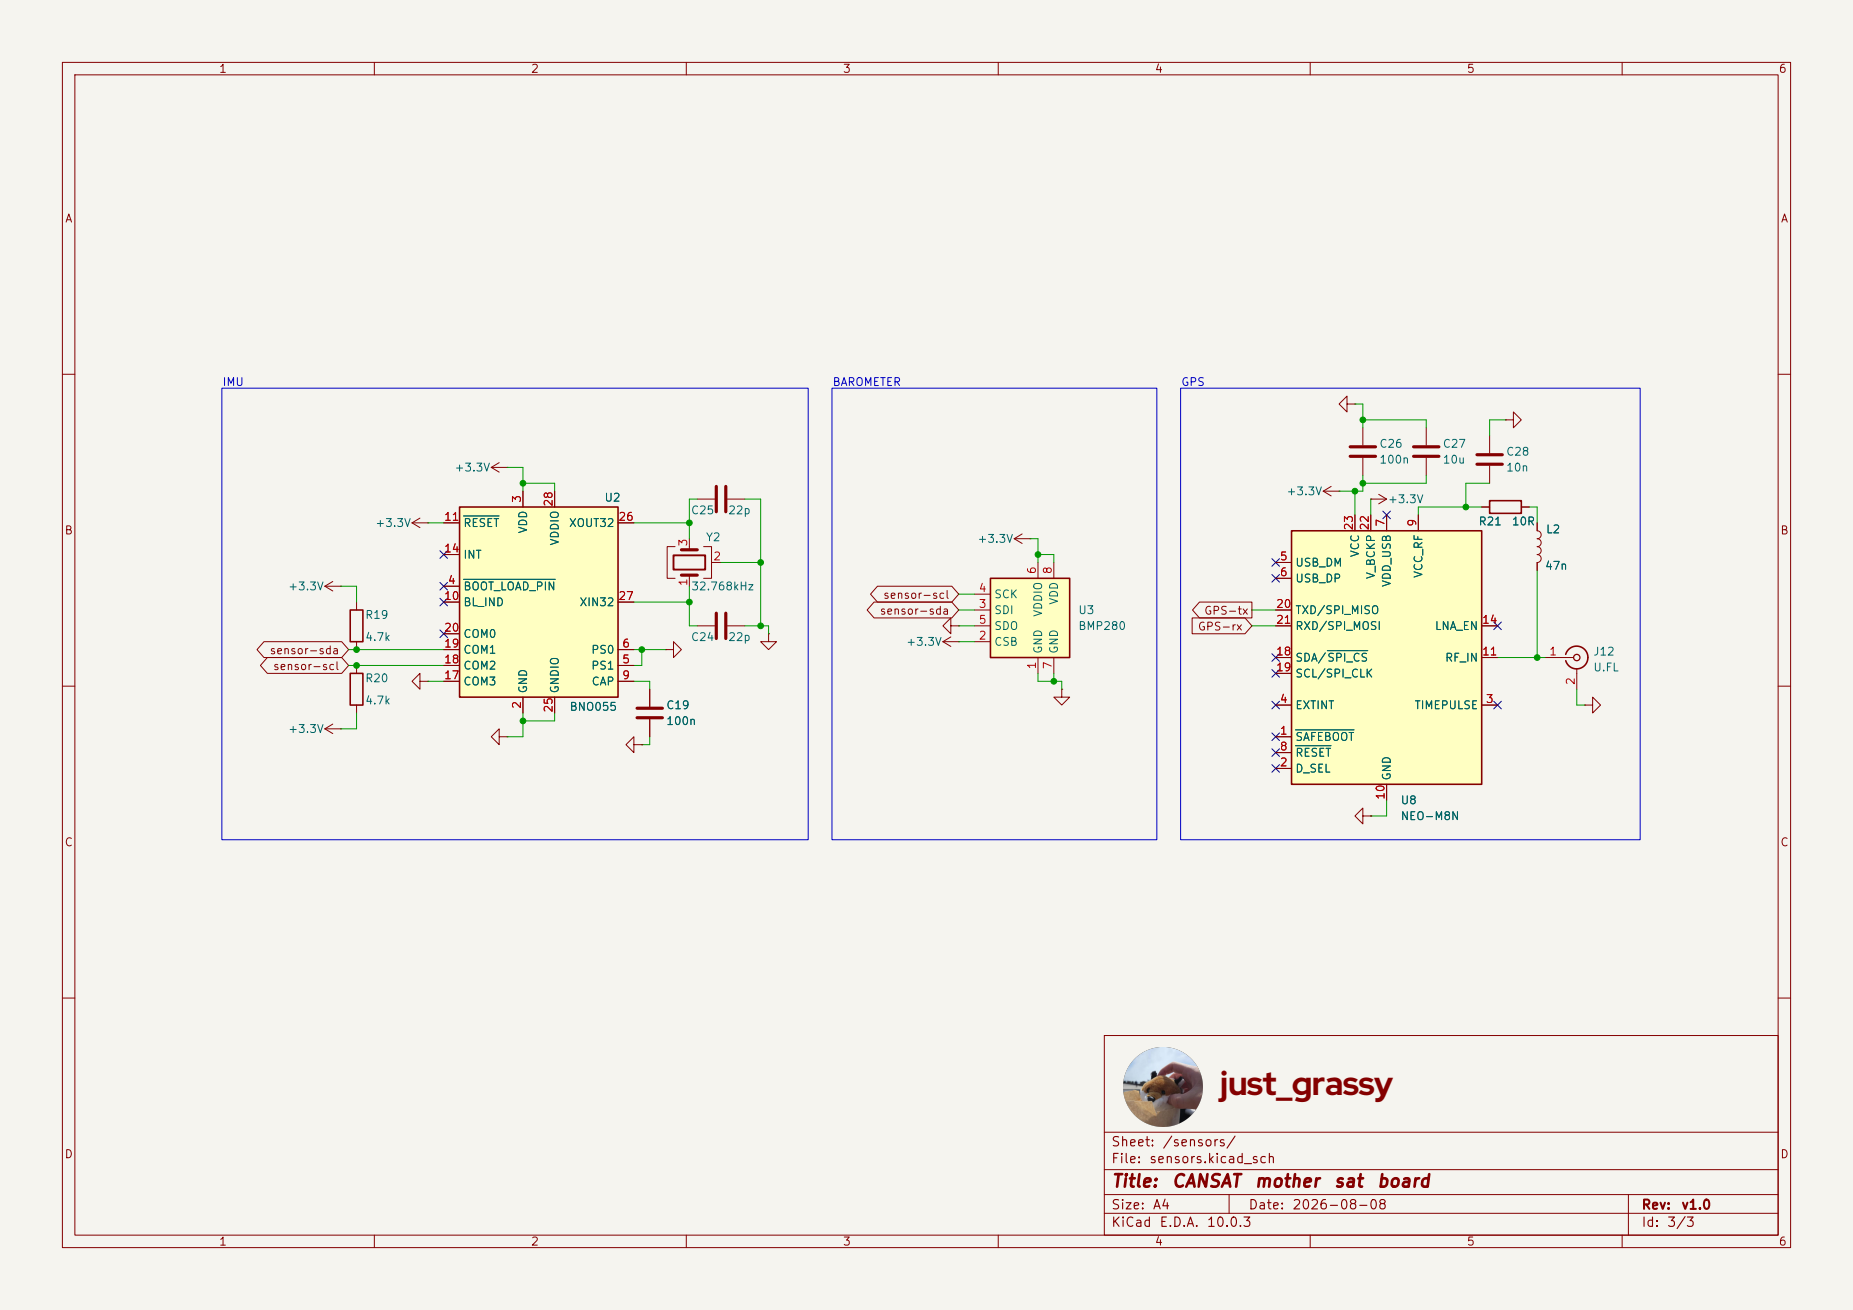
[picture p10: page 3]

8 U3BMP280 GPS-rx GPS-tx

sensor-scl sensor-sda

File: sensors.kicad_sch
Title: CANSAT mother sat board

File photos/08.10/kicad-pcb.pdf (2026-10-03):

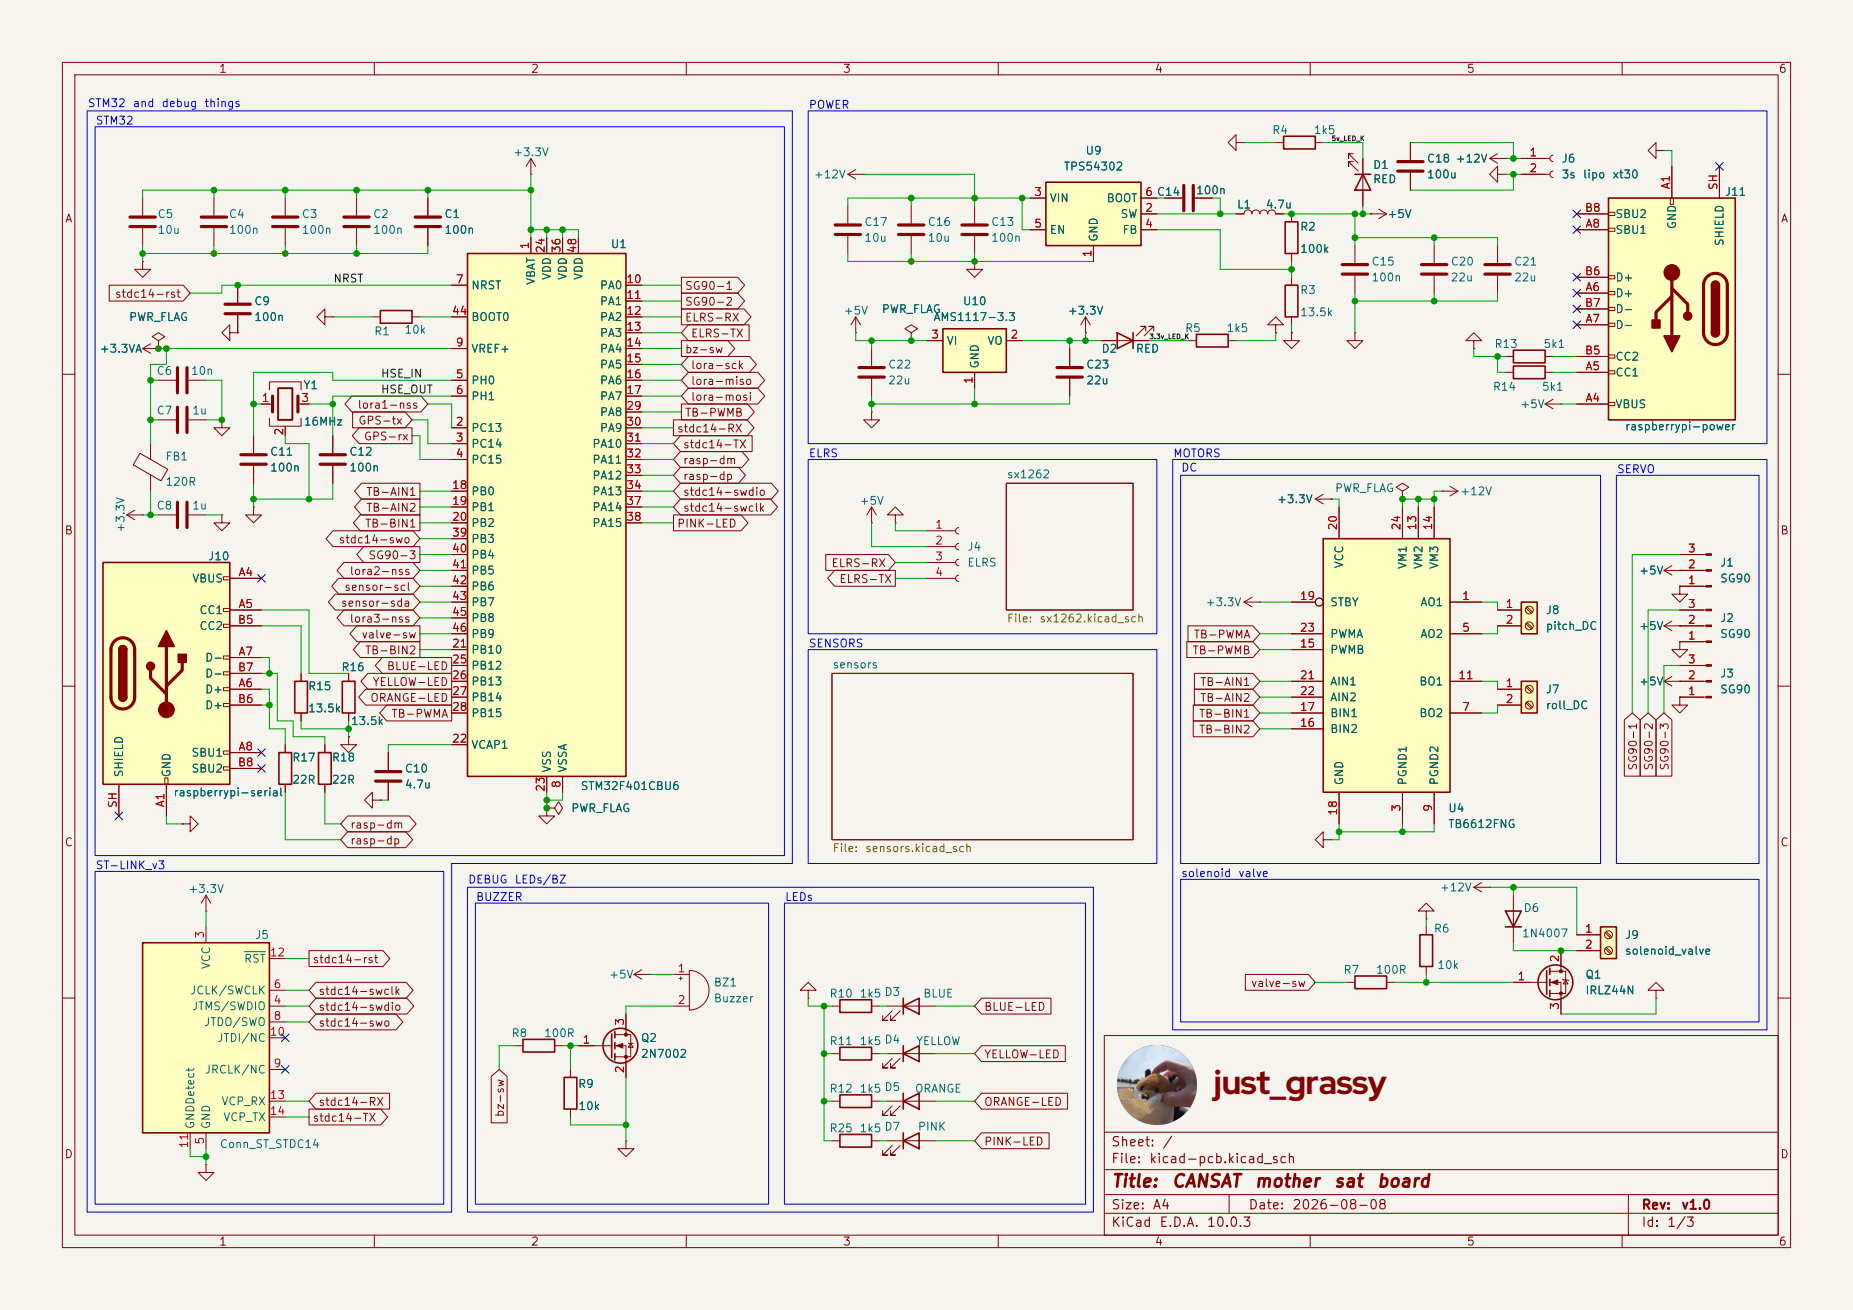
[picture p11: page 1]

lora-miso
lora-mosi TB-PWMB

YELLOW-LED ORANGE-LED

PINK-LED ORANGE-LED

Sheet: /
File: kicad-pcb.kicad_sch
Title: CANSAT mother sat board

Size: A4 | Rev: v1.0
KiCad E.D.A. 10.0.3 | Id: 1/3


lora-sck
lora-mosi lora-miso
lora-mosi lora1-nss

Sheet: /sx1262/
File: sx1262.kicad_sch
Title: CANSAT mother sat board


Sheet: /sensors/
File: sensors.kicad_sch
Title: CANSAT mother sat board

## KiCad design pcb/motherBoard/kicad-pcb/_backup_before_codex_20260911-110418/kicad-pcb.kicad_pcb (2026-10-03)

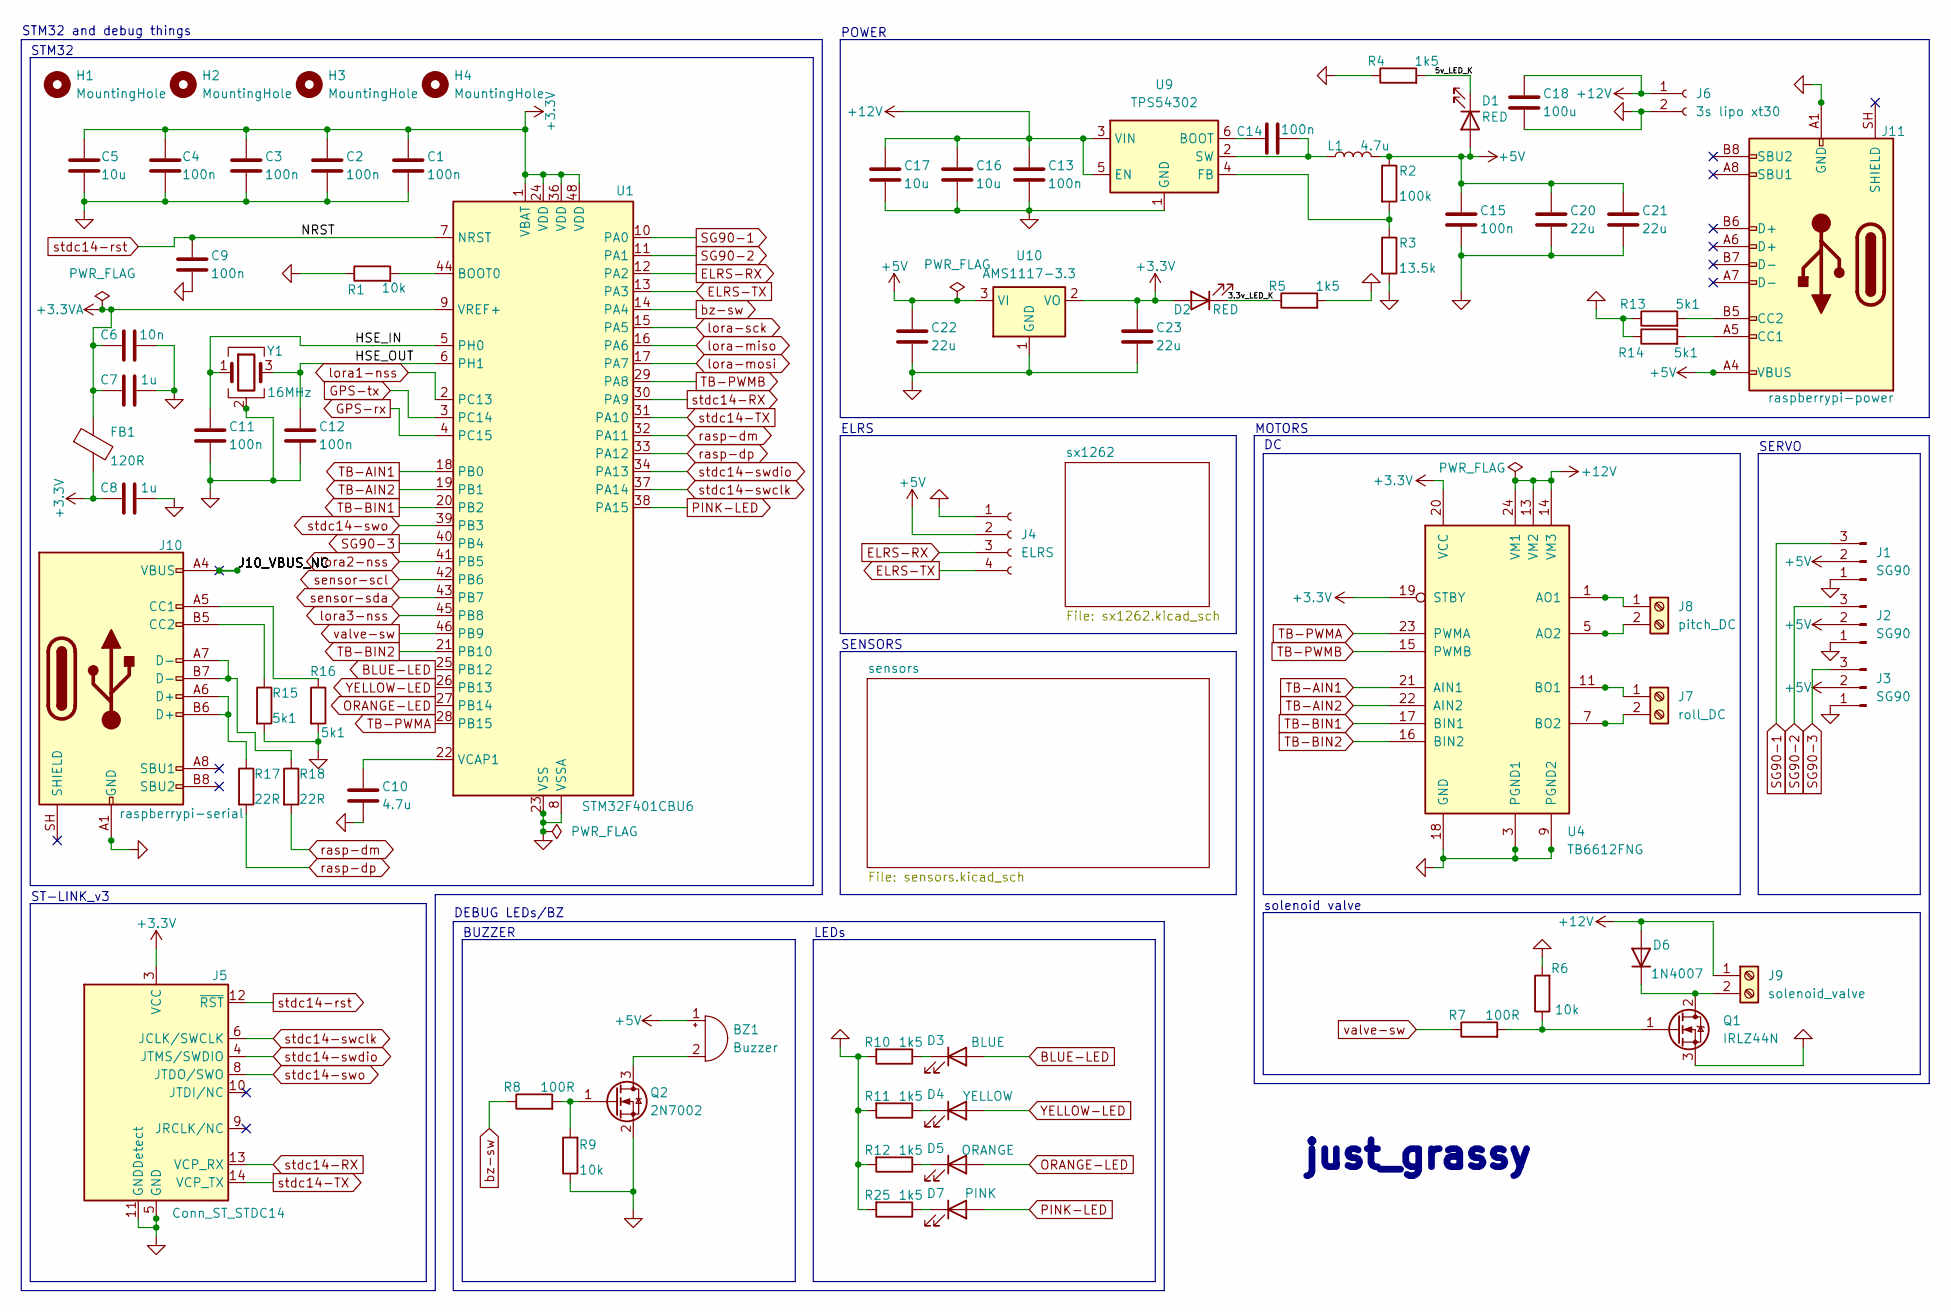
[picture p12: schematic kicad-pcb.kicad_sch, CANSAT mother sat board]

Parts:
BZ1: Buzzer; MagneticBuzzer_Kingstate_KCG0601
C1, C2, C3, C4, C9, C11, C12, C13, C14, C15: 100n; C_0402_1005Metric
C5, C16, C17: 10u; C_0603_1608Metric
C6: 10n; C_0603_1608Metric
C7, C8: 1u; C_0603_1608Metric
C10: 4.7u; C_0603_1608Metric
C18: 100u; C_0603_1608Metric
C20, C21, C22, C23: 22u; C_0603_1608Metric
D1, D2: RED; LED_0603_1608Metric
D3: BLUE; LED_0603_1608Metric
D4: YELLOW; LED_0603_1608Metric
D5: ORANGE; LED_0603_1608Metric
D6: 1N4007; D_DO-41_SOD81_P10.16mm_Horizontal
D7: PINK; LED_0603_1608Metric
FB1: 120R; L_0603_1608Metric
H1, H2, H3, H4: MountingHole; MountingHole_3.2mm_M3
J1, J2, J3: SG90; PinHeader_1x03_P2.54mm_Vertical
J4: ELRS; PinHeader_1x04_P2.54mm_Vertical
J5: Conn_ST_STDC14; PinHeader_2x07_P1.27mm_Vertical
J6: 3s lipo xt30; AMASS_XT30PW-F_1x02_P2.50mm_Horizontal
J7: roll_DC; TerminalBlock_MaiXu_MX126-5.0-02P_1x02_P5.00mm
J8: pitch_DC; TerminalBlock_MaiXu_MX126-5.0-02P_1x02_P5.00mm
J9: solenoid_valve; TerminalBlock_MaiXu_MX126-5.0-02P_1x02_P5.00mm
J10: raspberrypi-serial; USB_C_Receptacle_HRO_TYPE-C-31-M-12
J11: raspberrypi-power; USB_C_Receptacle_HRO_TYPE-C-31-M-12
L1: 4.7u; L_0603_1608Metric
Q1: IRLZ44N; TO-220-3_Vertical
Q2: 2N7002; SOT-23
R1, R6, R9: 10k; R_0402_1005Metric
R2: 100k; R_0402_1005Metric
R3: 13.5k; R_0402_1005Metric
R4, R5, R10, R11, R12, R25: 1k5; R_0402_1005Metric
R7, R8: 100R; R_0402_1005Metric
R13, R14, R15, R16: 5k1; R_0402_1005Metric
R17, R18: 22R; R_0402_1005Metric
U1: STM32F401CBU6; QFN-48-1EP_7x7mm_P0.5mm_EP5.6x5.6mm
U4: TB6612FNG; SSOP-24_5.3x8.2mm_P0.65mm
U9: TPS54302; SOT-23-6
U10: AMS1117-3.3; SOT-223-3_TabPin2
Y1: 16MHz; Crystal_SMD_3225-4Pin_3.2x2.5mm

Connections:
+3.3V: C1.1, C2.1, C3.1, C4.1, C5.1, C8.1, C23.1, D2.2 (A), FB1.2, J5.3 (VCC), U1.1 (VBAT), U1.24 (VDD), U1.36 (VDD), U1.48 (VDD), U4.19 (STBY), U4.20 (VCC), U10.2 (VO); also elsewhere on the board
+3.3VA: C6.1, C7.1, FB1.1, U1.9 (VREF+)
+5V: BZ1.1 (+), C15.1, C20.1, C21.1, C22.1, D1.2 (A), J1.2, J2.2, J3.2, J4.2, J11.A4 (VBUS), J11.A9 (VBUS), J11.B4 (VBUS), J11.B9 (VBUS), L1.2, R2.1, U10.3 (VI)
+12V: C13.1, C16.1, C17.1, C18.1, D6.2 (A), J6.1, J9.1, U4.13 (VM2), U4.14 (VM3), U4.24 (VM1), U9.3 (VIN), U9.5 (EN)
/3.3v_LED_K: D2.1 (K), R5.1
/5v_LED_K: D1.1 (K), R4.2
/HSE_IN: C11.1, U1.5 (PH0), Y1.1
/HSE_OUT: C12.1, U1.6 (PH1), Y1.3
BLUE-LED: D3.2 (A), U1.25 (PB12)
ELRS-RX: J4.3, U1.12 (PA2)
ELRS-TX: J4.4, U1.13 (PA3)
GND: C1.2, C2.2, C3.2, C4.2, C5.2, C6.2, C7.2, C8.2, C9.2, C10.2, C11.2, C12.2, C13.2, C15.2, C16.2, C17.2, C18.2, C20.2, C21.2, C22.2, C23.2, J1.1, J2.1, J3.1, J4.1, J5.5 (GND), J5.7 (GND), J5.11 (GNDDetect), J6.2, J10.A1 (GND), J10.A12 (GND), J10.B1 (GND), J10.B12 (GND), J11.A1 (GND), J11.A12 (GND), J11.B1 (GND), J11.B12 (GND), Q1.3 (S), Q2.2 (S), R1.1, R3.2, R4.1, R5.2, R6.2, R9.1, R10.2, R11.2, R12.2, R13.1, R14.1, R15.2, R16.2, R25.2, U1.8 (VSSA), U1.23 (VSS), U1.35 (VSS), U1.47 (VSS), U1.49 (VSS), U4.3 (PGND1), U4.4 (PGND1), U4.9 (PGND2), U4.10 (PGND2), U4.18 (GND), U9.1 (GND), U10.1 (GND), Y1.2 (G), Y1.4 (G); also elsewhere on the board
GPS-rx: U1.4 (PC15); also elsewhere on the board
GPS-tx: U1.3 (PC14); also elsewhere on the board
J10_VBUS_NC: J10.A4 (VBUS), J10.A9 (VBUS), J10.B4 (VBUS), J10.B9 (VBUS)
unnamed: BZ1.2 (-), Q2.3 (D)
unnamed: D3.1 (K), R10.1
unnamed: D4.1 (K), R11.1
unnamed: D5.1 (K), R12.1
unnamed: D6.1 (K), J9.2, Q1.2 (D)
unnamed: D7.1 (K), R25.1
unnamed: J7.1, U4.11 (BO1), U4.12 (BO1)
unnamed: J7.2, U4.7 (BO2), U4.8 (BO2)
unnamed: J8.1, U4.1 (AO1), U4.2 (AO1)
unnamed: J8.2, U4.5 (AO2), U4.6 (AO2)
unnamed: J10.A5 (CC1), R16.1
unnamed: J10.B5 (CC2), R15.1
unnamed: J10.A6 (D+), J10.B6 (D+), R17.1
unnamed: J10.A7 (D-), J10.B7 (D-), R18.1
unnamed: J11.A5 (CC1), R14.2
unnamed: J11.B5 (CC2), R13.2
unnamed: Q1.1 (G), R6.1, R7.2
unnamed: Q2.1 (G), R8.2, R9.2
unnamed: R1.2, U1.44 (BOOT0)
unnamed: C10.1, U1.22 (VCAP1)
unnamed: C14.1, U9.6 (BOOT)
unnamed: R2.2, R3.1, U9.4 (FB)
unnamed: C14.2, L1.1, U9.2 (SW)
ORANGE-LED: D5.2 (A), U1.27 (PB14)
PINK-LED: D7.2 (A), U1.38 (PA15)
SG90-1: J1.3, U1.10 (PA0)
SG90-2: J2.3, U1.11 (PA1)
SG90-3: J3.3, U1.40 (PB4)
TB-AIN1: U1.18 (PB0), U4.21 (AIN1)
TB-AIN2: U1.19 (PB1), U4.22 (AIN2)
TB-BIN1: U1.20 (PB2), U4.17 (BIN1)
TB-BIN2: U1.21 (PB10), U4.16 (BIN2)
TB-PWMA: U1.28 (PB15), U4.23 (PWMA)
TB-PWMB: U1.29 (PA8), U4.15 (PWMB)
YELLOW-LED: D4.2 (A), U1.26 (PB13)
bz-sw: R8.1, U1.14 (PA4)
lora1-nss: U1.2 (PC13); also elsewhere on the board
lora2-nss: U1.41 (PB5); also elsewhere on the board
lora3-nss: U1.45 (PB8); also elsewhere on the board
lora-miso: U1.16 (PA6); also elsewhere on the board
lora-mosi: U1.17 (PA7); also elsewhere on the board
lora-sck: U1.15 (PA5); also elsewhere on the board
rasp-dm: R18.2, U1.32 (PA11)
rasp-dp: R17.2, U1.33 (PA12)
sensor-scl: U1.42 (PB6); also elsewhere on the board
sensor-sda: U1.43 (PB7); also elsewhere on the board
stdc14-RX: J5.13 (VCP_RX), U1.30 (PA9)
stdc14-TX: J5.14 (VCP_TX), U1.31 (PA10)
stdc14-rst: C9.1, J5.12 (~RST), U1.7 (NRST)
stdc14-swclk: J5.6 (JCLK/SWCLK), U1.37 (PA14)
stdc14-swdio: J5.4 (JTMS/SWDIO), U1.34 (PA13)
stdc14-swo: J5.8 (JTDO/SWO), U1.39 (PB3)
valve-sw: R7.1, U1.46 (PB9)

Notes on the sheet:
MOTORS
SERVO
solenoid valve
LEDs
just_grassy
ELRS
POWER
STM32
BUZZER
SENSORS
DEBUG LEDs/BZ
STM32 and debug things
ST-LINK_v3

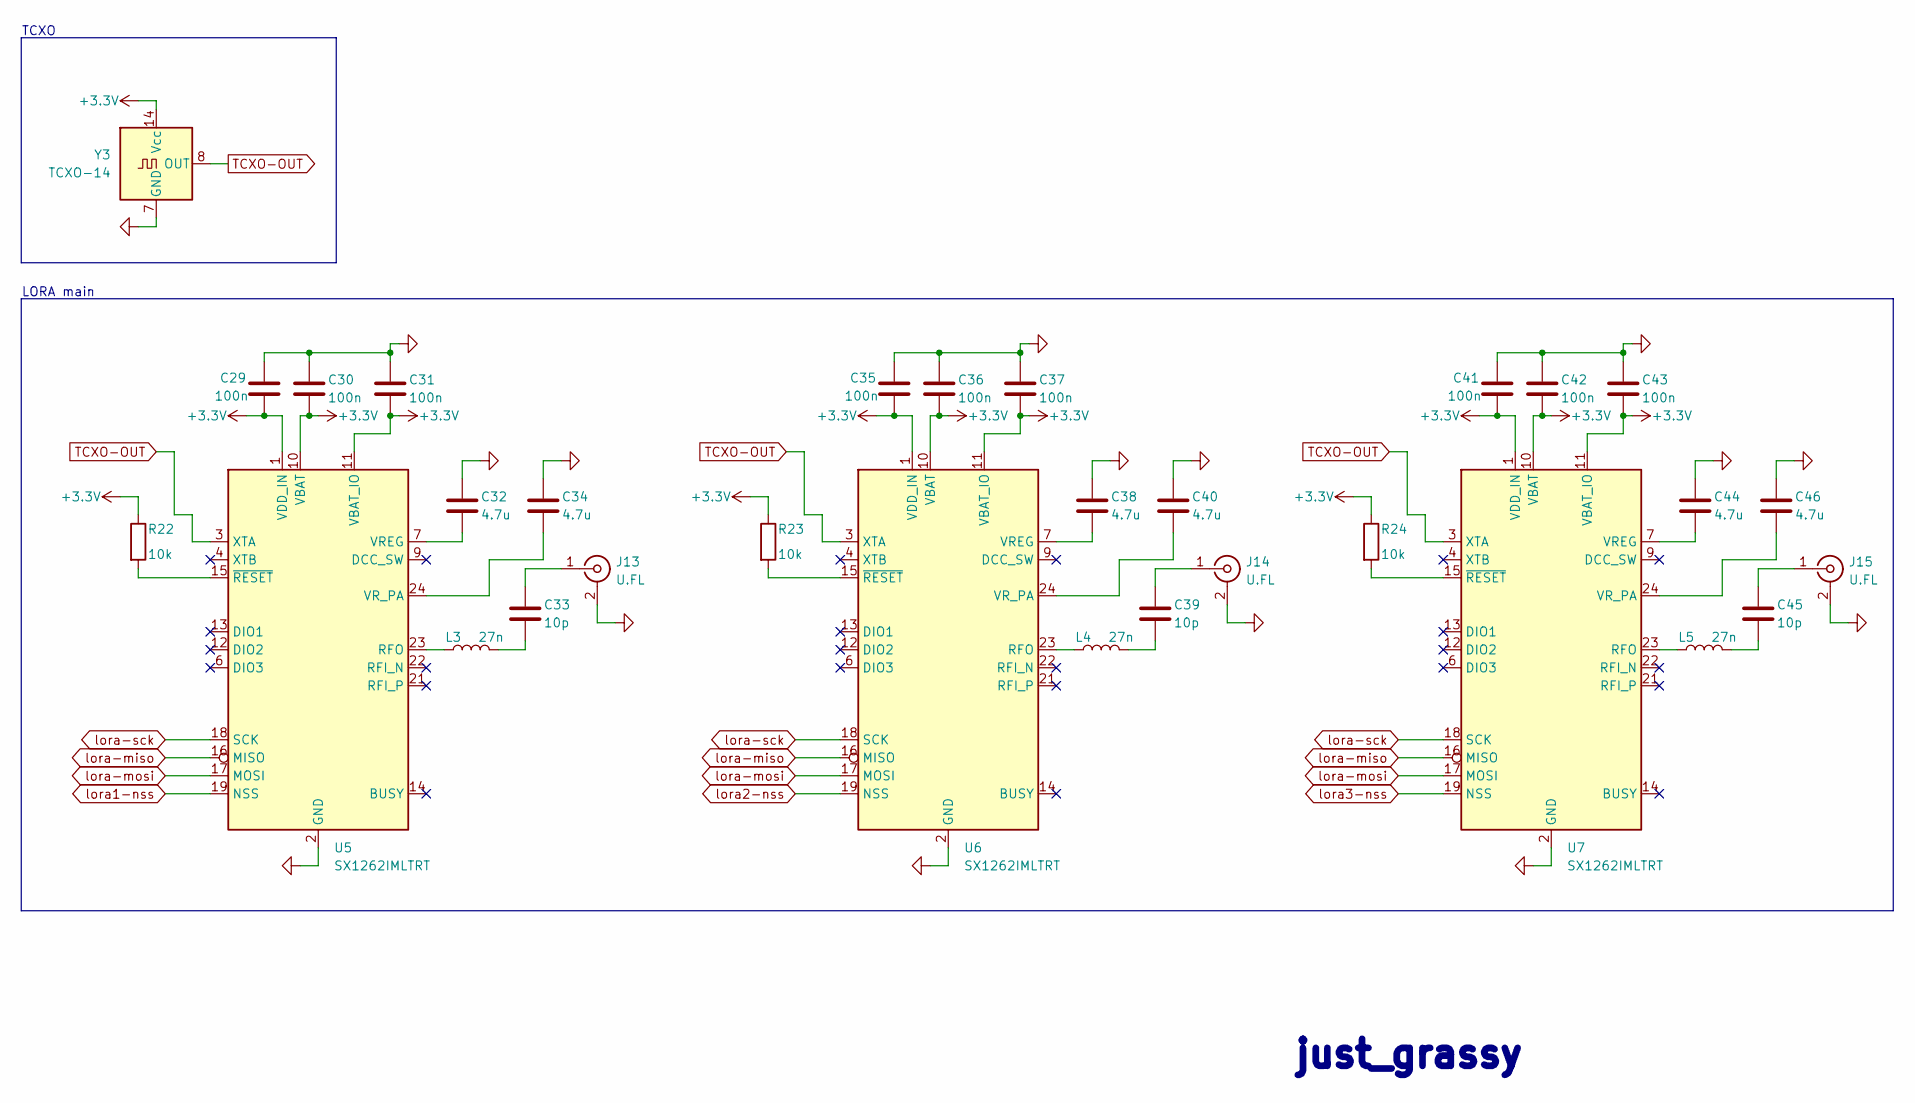
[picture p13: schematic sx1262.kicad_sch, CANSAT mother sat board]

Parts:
C29, C30, C31, C35, C36, C37, C41, C42, C43: 100n; C_0402_1005Metric
C32, C34, C38, C40, C44, C46: 4.7u; C_0603_1608Metric
C33, C39, C45: 10p; C_0402_1005Metric
J13, J14, J15: U.FL; IPEX-SMD_BWIPX-1-001E; LCSC C5137195
L3, L4, L5: 27n; L_0402_1005Metric
R22, R23, R24: 10k; R_0402_1005Metric
U5, U6, U7: SX1262IMLTRT; QFN-24-1EP_4x4mm_P0.5mm_EP2.6x2.6mm_ThermalVias; LCSC C191341
Y3: TCXO-14; Oscillator_DIP-14

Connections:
+3.3V: C29.2, C30.2, C31.2, C35.2, C36.2, C37.2, C41.2, C42.2, C43.2, R22.1, R23.1, R24.1, U5.1 (VDD_IN), U5.10 (VBAT), U5.11 (VBAT_IO), U6.1 (VDD_IN), U6.10 (VBAT), U6.11 (VBAT_IO), U7.1 (VDD_IN), U7.10 (VBAT), U7.11 (VBAT_IO), Y3.14 (Vcc); also elsewhere on the board
GND: C29.1, C30.1, C31.1, C32.1, C34.1, C35.1, C36.1, C37.1, C38.1, C40.1, C41.1, C42.1, C43.1, C44.1, C46.1, J13.2 (Ext), J14.2 (Ext), J15.2 (Ext), U5.2 (GND), U5.5 (GND), U5.8 (GND), U5.20 (GND), U5.25 (GND), U6.2 (GND), U6.5 (GND), U6.8 (GND), U6.20 (GND), U6.25 (GND), U7.2 (GND), U7.5 (GND), U7.8 (GND), U7.20 (GND), U7.25 (GND), Y3.7 (GND); also elsewhere on the board
unnamed: C33.2, L3.2
unnamed: C39.2, L4.2
unnamed: C45.2, L5.2
unnamed: C33.1, J13.1 (In)
unnamed: C39.1, J14.1 (In)
unnamed: C45.1, J15.1 (In)
unnamed: L3.1, U5.23 (RFO)
unnamed: C32.2, U5.7 (VREG)
unnamed: C34.2, U5.24 (VR_PA)
unnamed: R22.2, U5.15 (~RESET)
unnamed: L4.1, U6.23 (RFO)
unnamed: C38.2, U6.7 (VREG)
unnamed: C40.2, U6.24 (VR_PA)
unnamed: R23.2, U6.15 (~RESET)
unnamed: L5.1, U7.23 (RFO)
unnamed: C44.2, U7.7 (VREG)
unnamed: C46.2, U7.24 (VR_PA)
unnamed: R24.2, U7.15 (~RESET)
TCXO-OUT: U5.3 (XTA), U6.3 (XTA), U7.3 (XTA), Y3.8 (OUT)
lora1-nss: U5.19 (NSS); also elsewhere on the board
lora2-nss: U6.19 (NSS); also elsewhere on the board
lora3-nss: U7.19 (NSS); also elsewhere on the board
lora-miso: U5.16 (MISO), U6.16 (MISO), U7.16 (MISO); also elsewhere on the board
lora-mosi: U5.17 (MOSI), U6.17 (MOSI), U7.17 (MOSI); also elsewhere on the board
lora-sck: U5.18 (SCK), U6.18 (SCK), U7.18 (SCK); also elsewhere on the board

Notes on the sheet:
LORA main
TCXO
just_grassy

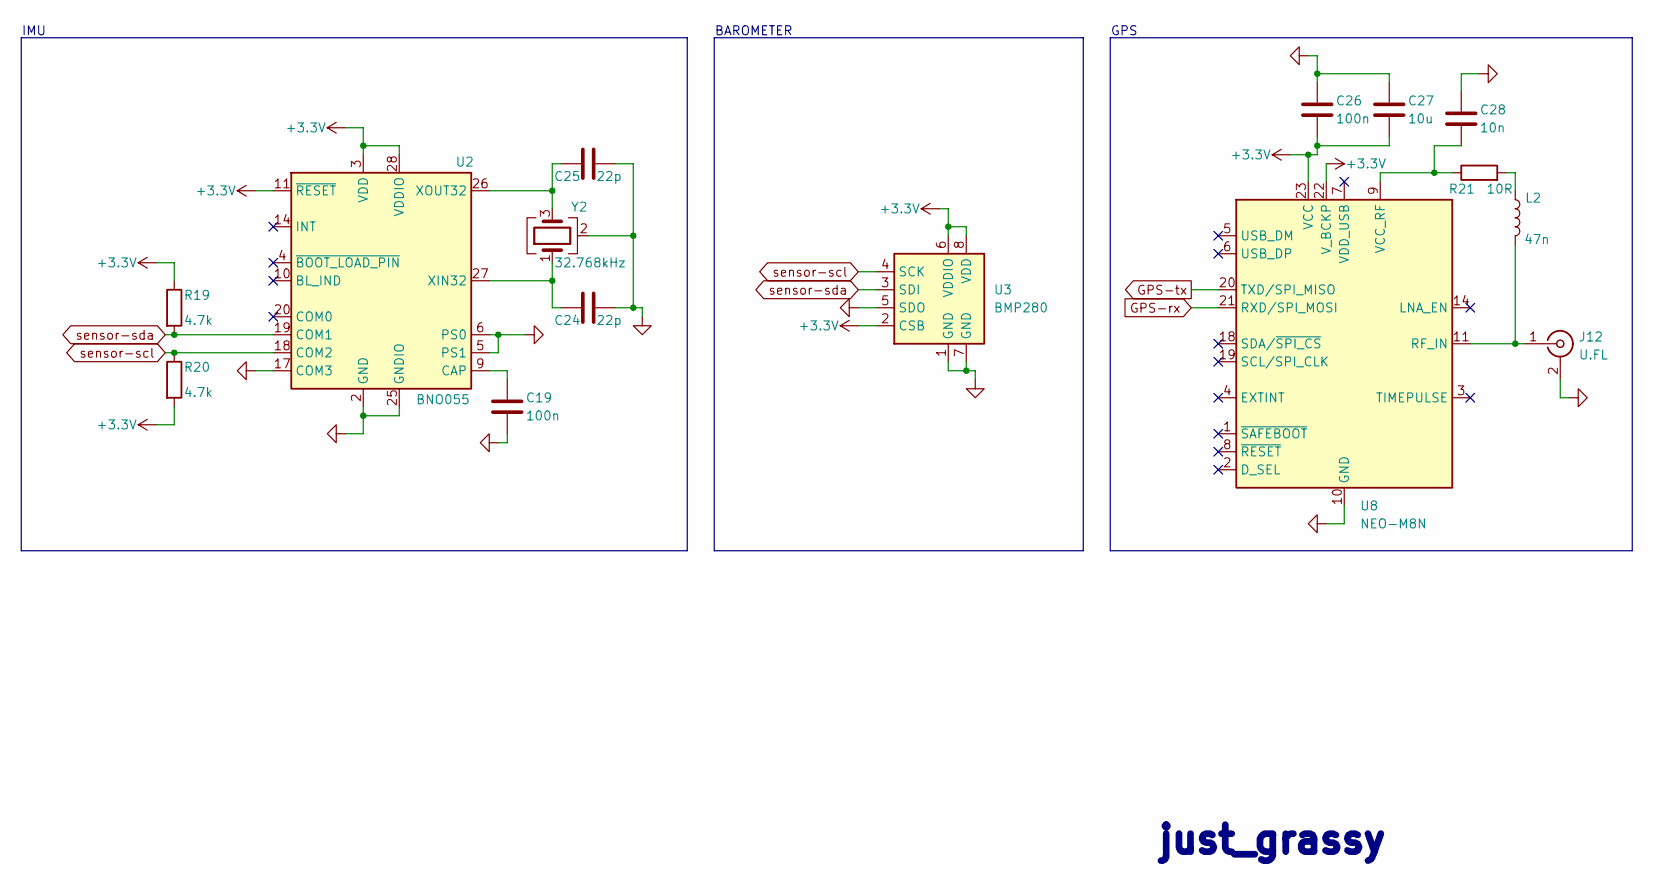
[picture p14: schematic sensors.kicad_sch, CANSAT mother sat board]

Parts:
C19, C26: 100n; C_0402_1005Metric
C24, C25: 22p; C_0402_1005Metric
C27: 10u; C_0603_1608Metric
C28: 10n; C_0402_1005Metric
J12: U.FL; IPEX-SMD_BWIPX-1-001E; LCSC C5137195
L2: 47n; L_0603_1608Metric
R19, R20: 4.7k; R_0402_1005Metric
R21: 10R; R_0402_1005Metric
U2: BNO055; LGA-28_5.2x3.8mm_P0.5mm
U3: BMP280; Bosch_LGA-8_2x2.5mm_P0.65mm_ClockwisePinNumbering
U8: NEO-M8N; ublox_NEO
Y2: 32.768kHz; Crystal_SMD_3225-4Pin_3.2x2.5mm

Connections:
+3.3V: C26.2, C27.2, R19.1, R20.2, U2.3 (VDD), U2.11 (~RESET), U2.28 (VDDIO), U3.2 (CSB), U3.6 (VDDIO), U3.8 (VDD), U8.22 (V_BCKP), U8.23 (VCC); also elsewhere on the board
GND: C19.2, C24.2, C25.2, C26.1, C27.1, C28.1, J12.2 (Ext), U2.2 (GND), U2.5 (PS1), U2.6 (PS0), U2.17 (COM3), U2.25 (GNDIO), U3.1 (GND), U3.5 (SDO), U3.7 (GND), U8.10 (GND), U8.12 (GND), U8.13 (GND), U8.24 (GND), Y2.2 (G), Y2.4 (G); also elsewhere on the board
GPS-rx: U8.21 (RXD/SPI_MOSI); also elsewhere on the board
GPS-tx: U8.20 (TXD/SPI_MISO); also elsewhere on the board
unnamed: J12.1 (In), L2.2, U8.11 (RF_IN)
unnamed: L2.1, R21.2
unnamed: C19.1, U2.9 (CAP)
unnamed: C24.1, U2.27 (XIN32), Y2.1
unnamed: C25.1, U2.26 (XOUT32), Y2.3
unnamed: C28.2, R21.1, U8.9 (VCC_RF)
sensor-scl: R20.1, U2.18 (COM2), U3.4 (SCK); also elsewhere on the board
sensor-sda: R19.2, U2.19 (COM1), U3.3 (SDI); also elsewhere on the board

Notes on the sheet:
BAROMETER
GPS
just_grassy
IMU

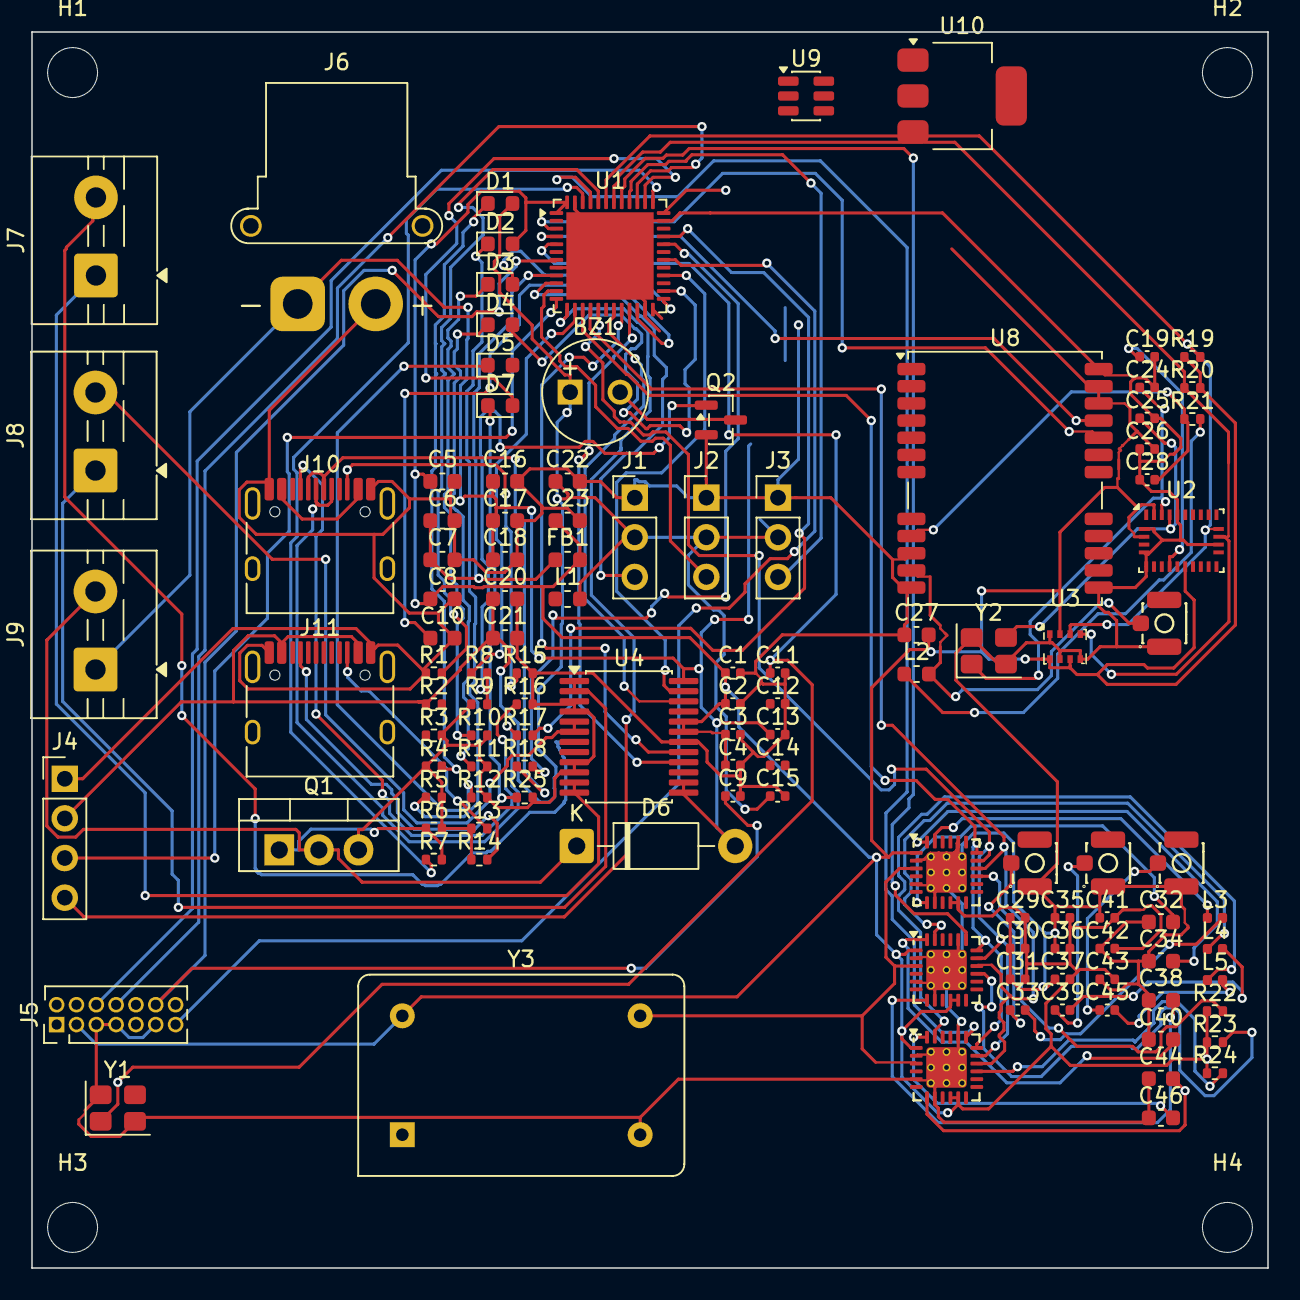
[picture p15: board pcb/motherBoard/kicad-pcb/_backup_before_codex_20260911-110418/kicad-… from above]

Board: 2 copper layers, 79.2 x 79.2 mm, 119 parts (0 on the bottom side), 93 nets.

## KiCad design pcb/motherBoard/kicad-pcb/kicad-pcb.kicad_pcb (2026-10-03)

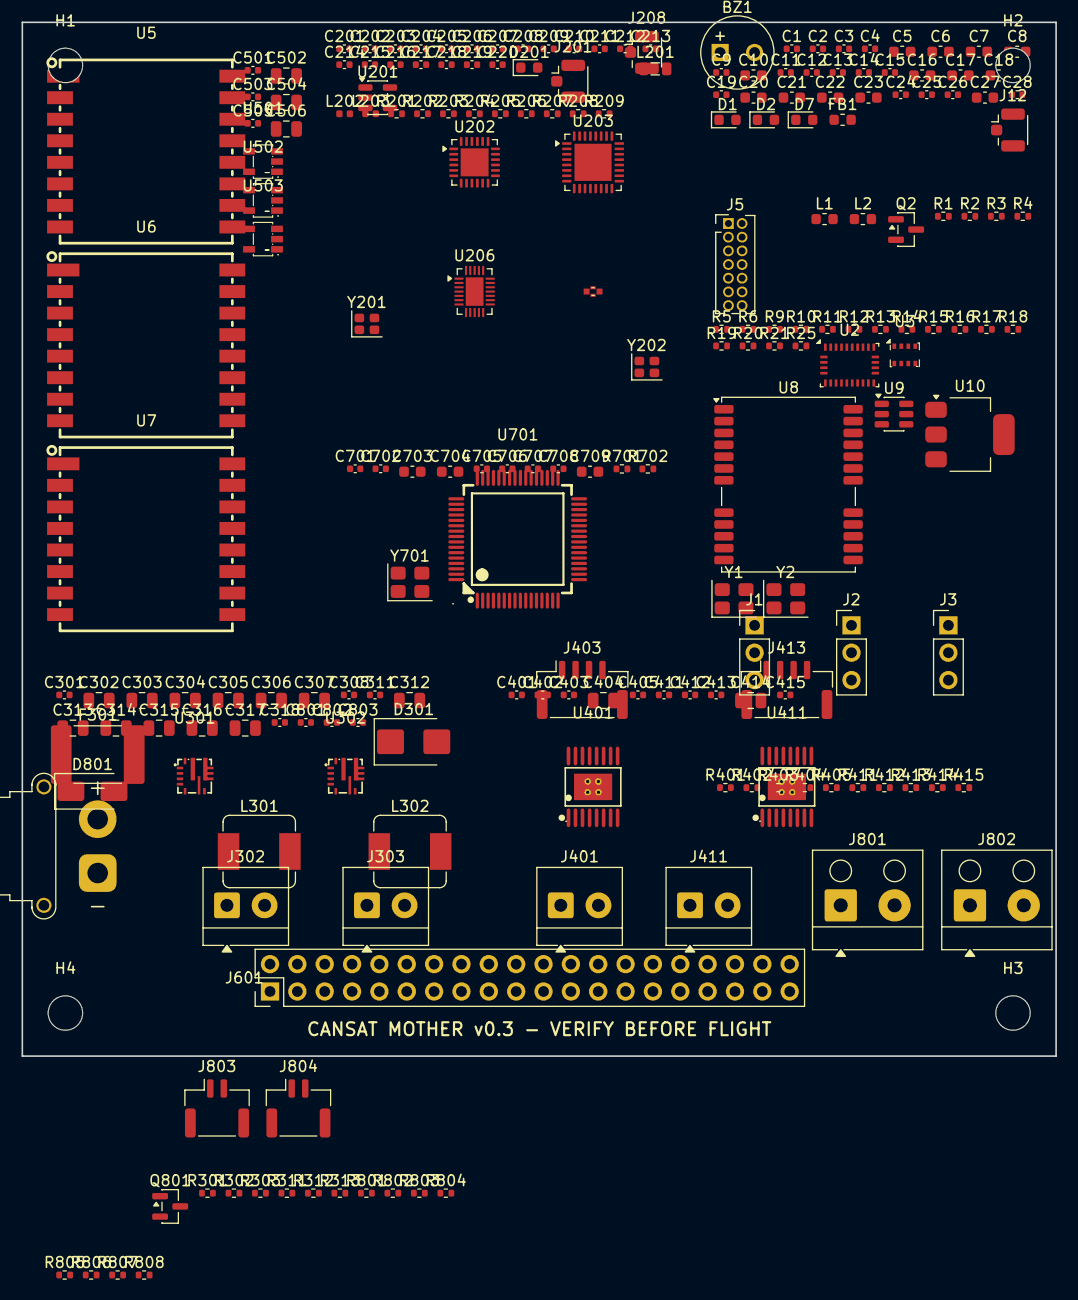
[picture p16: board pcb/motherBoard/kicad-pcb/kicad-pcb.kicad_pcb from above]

Board: 4 copper layers, 96.0 x 96.0 mm, 214 parts (0 on the bottom side), 107 nets, no tracks yet.

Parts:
BZ1: Buzzer; MagneticBuzzer_Kingstate_KCG0601
C1, C2, C3, C4, C9, C13, C14, C15, C19, C26, C206, C207, C211, C218, C501, C503, C505, C705, C706, C707, C708: 100n; C_0402_1005Metric
C5, C16, C17, C27: 10u; C_0603_1608Metric
C6: 10n; C_0603_1608Metric
C7, C8: 1u; C_0603_1608Metric
C10, C709: 4.7u; C_0603_1608Metric
C11, C12: 12p; C_0402_1005Metric
C18: 100u; C_0603_1608Metric
C20, C21, C22, C23: 22u; C_0603_1608Metric
C24, C25: 22p; C_0402_1005Metric
C28, C203, C205, C405, C415: 10n; C_0402_1005Metric
C201: 1u; C_0402_1005Metric
C202: 2.2u; C_0402_1005Metric
C204: 470n, 10V; C_0402_1005Metric
C208, C209, C217, C219: 10p; C_0402_1005Metric
C210, C213: 1u 25v; C_0402_1005Metric
C212: 10u; C_0402_1005Metric
C214, C215, C216, C220: 1.2p; C_0402_1005Metric
C301, C311: 100n 25V; C_0402_1005Metric
C302, C303, C312, C313, C404, C414: 10u 25V C89831; C_0805_2012Metric
C304, C305, C306, C307, C314, C315, C316, C317: 22u 16V; C_0805_2012Metric
C308, C318: 100p C0G; C_0402_1005Metric
C401, C411: 22n 25V X7R; C_0402_1005Metric
C402, C412: 100n 16V X7R; C_0402_1005Metric
C403, C413: 100n 25V X7R; C_0402_1005Metric
C502, C504, C506: 10u; C_0805_2012Metric
C701, C702: 12p C1547; C_0402_1005Metric
C703, C704: 2.2u 10V; C_0603_1608Metric
C801: 100n 50V C1525; C_0402_1005Metric
C802, C803: 100n C1525; C_0402_1005Metric
D1, D2: RED; LED_0603_1608Metric
D7: PINK; LED_0603_1608Metric
D201: LED; LED_0603_1608Metric
D301: SMBJ18A; D_SMB
D801: SS34 C8678; D_SMA
F301: 10A resettable/polyfuse; Fuse_2920_7451Metric
FB1: 120R; L_0603_1608Metric
H1, H2, H3, H4: MountingHole; MountingHole_3.2mm_M3
J1, J2, J3: SG90; PinHeader_1x03_P2.54mm_Vertical
J5: Conn_ST_STDC14; PinHeader_2x07_P1.27mm_Vertical
J12: U.FL; U.FL_Hirose_U.FL-R-SMT-1_Vertical
J201, J208: Conn_Coaxial; U.FL_Hirose_U.FL-R-SMT-1_Vertical
J301: 3S_LIPO_INPUT; AMASS_XT30PW-F_1x02_P2.50mm_Horizontal
J302: PI5_5V1_OUT; TerminalBlock_4Ucon_1x02_P3.50mm_Horizontal
J303: SERVO_6V_OUT; TerminalBlock_4Ucon_1x02_P3.50mm_Horizontal
J401: REACTION_WHEEL_X; TerminalBlock_4Ucon_1x02_P3.50mm_Horizontal
J403: ENCODER_X; JST_GH_SM04B-GHS-TB_1x04-1MP_P1.25mm_Horizontal
J411: REACTION_WHEEL_Y; TerminalBlock_4Ucon_1x02_P3.50mm_Horizontal
J413: ENCODER_Y; JST_GH_SM04B-GHS-TB_1x04-1MP_P1.25mm_Horizontal
J601: RASPBERRY_PI_5_GPIO; PinHeader_2x20_P2.54mm_Vertical
J801: ARM KEY; Altech_AK100_1x02_P5.00mm
J802: 12V VALVE; Altech_AK100_1x02_P5.00mm
J803: DEPLOY SWITCH; JST_GH_SM02B-GHS-TB_1x02-1MP_P1.25mm_Horizontal
J804: RECOVERY INPUT; JST_GH_SM02B-GHS-TB_1x02-1MP_P1.25mm_Horizontal
L1: 4.7u; L_0603_1608Metric
L2: 47n; L_0603_1608Metric
L201: 15u; L_0805_2012Metric
L202, L203: 3n; L_0402_1005Metric
L301, L302: 3.3uH 12A C7461388; L_Sumida_CDMC6D28_7.25x6.5mm
Q2: 2N7002; SOT-23
Q801: AO3400A C20917; SOT-23
R1, R6, R9, R202, R207, R208, R209, R405, R415, R702: 10k; R_0402_1005Metric
R2, R201, R303, R313, R701: 100k; R_0402_1005Metric
R3: 13.5k; R_0402_1005Metric
R4, R5, R10, R11, R12, R25: 1k5; R_0402_1005Metric
R13, R14, R15, R16: 5k1; R_0402_1005Metric
R17, R18: 22R; R_0402_1005Metric
R19, R20: 4.7k; R_0402_1005Metric
R21: 10R; R_0402_1005Metric
R203: 2.2k; R_0402_1005Metric
R204: 1.2k; R_0402_1005Metric
R205: 3.3k; R_0402_1005Metric
R206: 12k; R_0402_1005Metric
R301: 75k 1%; R_0402_1005Metric
R302, R312: 10k 1%; R_0402_1005Metric
R311: 90k 1%; R_0402_1005Metric
R401, R411: 5.6k 1%; R_0402_1005Metric
R402, R412: 16k 1%; R_0402_1005Metric
R403, R413: 50k 1%; R_0402_1005Metric
R404, R414: 20k 1%; R_0402_1005Metric
R801, R805: 100k 1% C25741; R_0402_1005Metric
R802, R806: 27k 1% C25771; R_0402_1005Metric
R803: 100R C25076; R_0402_1005Metric
R804: 100k C25741; R_0402_1005Metric
R807, R808: 10k C25744; R_0402_1005Metric
U2: BNO055; LGA-28_5.2x3.8mm_P0.5mm
U3: BMP280; Bosch_LGA-8_2x2.5mm_P0.65mm_ClockwisePinNumbering
U5: Ra-01SH C2764087 CHILD_1; WIRELM-SMD_RA-01SH
U6: Ra-01SH C2764087 CHILD_2; WIRELM-SMD_RA-01SH
U7: Ra-01SH C2764087 CHILD_3; WIRELM-SMD_RA-01SH
U8: NEO-M8N; ublox_NEO
U9: TPS54302; SOT-23-6
U10: AMS1117-3.3; SOT-223-3_TabPin2
U201: 3V3. 500mA; TSOT-23-5
U202: SX1281; QFN-24-1EP_4x4mm_P0.5mm_EP2.6x2.6mm
U203: ESP8285; QFN-32-1EP_5x5mm_P0.5mm_EP3.45x3.45mm
U204: 2450FM07D0034T; 2450FM07D0034
U206: SE2431L; QFN-24-1EP_3x4mm_P0.4mm_EP1.65x2.65mm
U301: TPS56637RPAR (5.1V/6A); VQFN-HR-10_L3.0-W3.0_RPA
U302: TPS56637RPAR (6.0V/4A); VQFN-HR-10_L3.0-W3.0_RPA
U401, U411: DRV8874PWPR C1855818; HTSSOP-16_L5.0-W4.4-P0.65-LS6.4-BL-EP
U501, U502, U503: SN74LVC1G04DBVR C434067; SOT-23-5_L3.0-W1.7-P0.95-LS2.8-BR
U701: STM32F405RGT6 C15742; LQFP-64_L10.0-W10.0-P0.50-LS12.0-BL
Y1: 16MHz; Crystal_SMD_3225-4Pin_3.2x2.5mm
Y2: 32.768kHz; Crystal_SMD_3225-4Pin_3.2x2.5mm
Y201: 26M; Crystal_SMD_2016-4Pin_2.0x1.6mm
Y202: 52Mhz, 8pF; Crystal_SMD_2016-4Pin_2.0x1.6mm
Y701: 16MHz C13738; Crystal_SMD_3225-4Pin_3.2x2.5mm

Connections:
3.3v_LED_K: D2.1, R5.1
+3.3V: C1.1, C2.1, C3.1, C4.1, C5.1, C8.1, C23.1, C26.2, C27.2, C202.2, C206.2, C207.2, C211.2, C212.2, C213.1, C217.2, C218.1, C219.1, D2.2, FB1.2, J5.3, R19.1, R20.2, R202.2, R207.2, R209.1, U2.3, U2.11, U2.28, U3.2, U3.6, U3.8, U5.1, U6.1, U7.1, U8.22, U8.23, U10.2, U201.5, U202.11, U202.15, U203.1, U203.3, U203.4, U203.11, U203.17, U203.29, U203.30, U203.32, U206.19, U206.20, U206.21, U206.22
+3V3: C501.1, C502.1, C503.1, C504.1, C505.1, C506.1, C705.1, C706.1, C707.1, C708.1, C709.1, J403.1, J413.1, R402.1, R405.1, R412.1, R415.1, R702.1, R807.1, R808.1, U5.3, U6.3, U7.3, U501.5, U502.5, U503.5, U701.1, U701.13, U701.19, U701.32, U701.48, U701.64
+5V: BZ1.1, C15.1, C20.1, C21.1, C22.1, D1.2, L1.2, R2.1
+12V: C13.1, C16.1, C17.1, C18.1, U9.3, U9.5
ANT1: C214.1, L202.1, U206.15
ANT2: C215.1, L203.1, U206.13
ANT_SEL: U203.18, U206.16
ARM_SENSE: R805.2, R806.1, U701.3
BATTERY_SENSE: C801.1, R801.2, R802.1, U701.14
BAT_IN_PLUS: F301.1, J301.1
BOOT: R209.2, U203.15
BOOT0: R701.1, U701.60
BUSY: U202.7, U203.24
CS: R208.1, U202.19, U203.13
DEPLOY_SENSE: C802.1, J803.1, R807.2, U701.4
DIO: U202.8, U203.16
ENCODER_X_A: J403.3, U701.8
ENCODER_X_B: J403.4, U701.9
ENCODER_Y_A: J413.3, U701.10
ENCODER_Y_B: J413.4, U701.11
FRONTEND_IN: U204.3, U206.6
GND: C1.2, C2.2, C3.2, C4.2, C5.2, C6.2, C7.2, C8.2, C9.2, C10.2, C11.2, C12.2, C13.2, C15.2, C16.2, C17.2, C18.2, C19.2, C20.2, C21.2, C22.2, C23.2, C24.2, C25.2, C26.1, C27.1, C28.1, C201.1, C202.1, C203.1, C204.2, C205.1, C206.1, C207.1, C208.1, C209.1, C210.2, C211.1, C212.1, C213.2, C214.2, C215.2, C216.2, C217.1, C218.2, C219.2, C220.2, C302.2, C303.2, C304.2, C305.2, C306.2, C307.2, C312.2, C313.2, C314.2, C315.2, C316.2, C317.2, C403.2, C404.2, C405.2, C413.2, C414.2, C415.2, C501.2, C502.2, C503.2, C504.2, C505.2, C506.2, C701.2, C702.2, C703.2, C704.2, C705.2, C706.2, C707.2, C708.2, C709.2, C801.2, C802.2, C803.2, D201.1, D301.2, J1.1, J2.1, J3.1, J5.5, J5.7, J5.11, J12.2, J201.2, J208.2, J301.2, J302.2, J303.2, J403.2, J413.2, J601.6, J601.9, J601.14, J601.20, J601.25, J601.30, J601.34, J601.39, J803.2, J804.2, Q2.2, Q801.2, R1.1, R3.2, R4.1, R5.2, R6.2, R9.1, R10.2, R11.2, R12.2, R13.1, R14.1, R15.2, R16.2, R25.2, R201.2, R206.2, R208.2, R302.2, R312.2, R401.2, R403.2, R404.2, R411.2, R413.2, R414.2, R701.2, R802.2, R804.2, R806.2, U2.2, U2.5, U2.6, U2.17, U2.25, U3.1, U3.5, U3.7, U5.2, U5.8, U5.9, U5.16, U6.2, U6.8, U6.9, U6.16, U7.2, U7.8, U7.9, U7.16, U8.10, U8.12, U8.13, U8.24, U9.1, U10.1, U201.2, U202.5, U202.13, U202.20, U202.21, U202.23, U202.24, U202.25, U203.33, U204.2, U204.4, U206.9, U206.10, U206.11, U206.12, U206.14, U206.18, U206.25, U301.3, U301.9, U301.10, U302.3, U302.9, U302.10, U401.9, U401.15, U401.16, U401.17, U411.9, U411.15, U411.16, U411.17, U501.3, U502.3, U503.3, U701.12, U701.18, U701.63, Y1.2, Y1.4, Y2.2, Y2.4, Y201.2, Y201.4, Y202.2, Y202.4
GPS-rx: U8.21, U701.38
GPS-tx: U8.20, U701.37
HSE_IN: C701.1, U701.5, Y701.1
HSE_OUT: C702.1, U701.6, Y701.2
LORA1_BUSY: U5.10, U701.25
LORA1_DIO1: U5.6, U701.39
LORA1_NSS: U5.15, U701.24
LORA1_RFSW_RX: U5.11, U501.4
LORA1_RFSW_TX: U5.5, U5.7, U501.2
LORA2_BUSY: U6.10, U701.50
LORA2_DIO1: U6.6, U701.51
LORA2_NSS: U6.15, U701.40
LORA2_RFSW_RX: U6.11, U502.4
LORA2_RFSW_TX: U6.5, U6.7, U502.2
LORA3_BUSY: U7.10, U701.53
LORA3_DIO1: U7.6, U701.54
LORA3_NSS: U7.15, U701.52
LORA3_RFSW_RX: U7.11, U503.4
LORA3_RFSW_TX: U7.5, U7.7, U503.2
LORA_RESET_N: U5.4, U6.4, U7.4, U701.62
LORA_SPI_MISO: U5.13, U6.13, U7.13, U701.22
LORA_SPI_MOSI: U5.14, U6.14, U7.14, U701.23
LORA_SPI_SCK: U5.12, U6.12, U7.12, U701.21
MISO: U202.16, U203.10
MOSI: U202.17, U203.12
MOTOR_ENABLE: U401.3, U411.3, U701.33
MOTOR_X_CPH: C401.1, U401.13
MOTOR_X_CPL: C401.2, U401.14
MOTOR_X_CURRENT: C405.1, R401.1, U401.6, U701.15
MOTOR_X_DIR: U401.2, U701.56
MOTOR_X_FAULT_N: R405.2, U401.4, U701.34
MOTOR_X_IMODE: R404.1, U401.7
MOTOR_X_OUT1: J401.1, U401.8
MOTOR_X_OUT2: J401.2, U401.10
MOTOR_X_PWM: U401.1, U701.41
MOTOR_X_VCP: C402.1, U401.12
MOTOR_X_VREF: R402.2, R403.1, U401.5
MOTOR_Y_CPH: C411.1, U411.13
MOTOR_Y_CPL: C411.2, U411.14
MOTOR_Y_CURRENT: C415.1, R411.1, U411.6
MOTOR_Y_DIR: U411.2, U701.30
MOTOR_Y_FAULT_N: R415.2, U411.4, U701.35
MOTOR_Y_IMODE: R414.1, U411.7
MOTOR_Y_OUT1: J411.1, U411.8
MOTOR_Y_OUT2: J411.2, U411.10
MOTOR_Y_PWM: U411.1, U701.29
MOTOR_Y_VCP: C412.1, U411.12
MOTOR_Y_VREF: R412.2, R413.1, U411.5
PI5_5V1: C304.1, C305.1, C306.1, C307.1, C308.1, J302.1, J601.2, J601.4, L301.2, R301.1
PI5_BOOT: C301.1, U301.7
PI5_EN: R303.2, U301.1
PI5_FB: C308.2, R301.2, R302.1, U301.2
PI5_SW: C301.2, L301.1, U301.6
PI_UART_RX: J5.14, J601.8, U701.43
PI_UART_TX: J5.13, J601.10, U701.42
PWR_FLAG: C6.1, C7.1, FB1.1, U10.3
PWR_IN: C201.2, U201.1, U201.3
PWR_TXEN: R201.1, U203.19, U206.24
RADIO_OUT: U202.22, U204.1
RAW_BAT: C302.1, C303.1, C312.1, C313.1, C402.2, C403.1, C404.1, C412.2, C413.1, C414.1, D301.1, F301.2, J801.1, R303.1, R313.1, R801.1, U301.8, U302.8, U401.11, U411.11
RECOVERY_INPUT: C803.1, J804.1, R808.2, U701.57
RST: R207.1, U202.3, U203.14
SCK: U202.18, U203.9
SERVO_6V0: C314.1, C315.1, C316.1, C317.1, C318.1, J1.2, J2.2, J3.2, J303.1, L302.2, R311.1
SERVO_BOOT: C311.1, U302.7
SERVO_EN: R313.2, U302.1
SERVO_FB: C318.2, R311.2, R312.1, U302.2
SERVO_SW: C311.2, L302.1, U302.6
SG90-1: J1.3, U701.26
SG90-2: J2.3, U701.27
SG90-3: J3.3, U701.28
VALVE_ARMED: D801.1, J801.2, J802.1, R805.1
VALVE_GATE: Q801.1, R803.2, R804.1
VALVE_SW_NODE: D801.2, J802.2, Q801.3
VCAP1: C703.1, U701.31
VCAP2: C704.1, U701.47
V_DCC2: L201.2, U202.14
sensor-scl: R20.1, U2.18, U3.4, U701.58
sensor-sda: R19.2, U2.19, U3.3, U701.59
stdc14-rst: C9.1, J5.12, R702.2, U701.7
stdc14-swclk: J5.6, U701.49
stdc14-swdio: J5.4, U701.46
stdc14-swo: J5.8, U701.55
valve-sw: R803.1, U701.20

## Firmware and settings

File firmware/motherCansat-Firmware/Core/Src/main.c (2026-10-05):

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
/* Includes ------------------------------------------------------------------*/
#include "main.h"

/* USER CODE BEGIN Includes */
#include <stdio.h>
#include "imu/imu.h"
#include "crsf/crsf.h"
#include "crsf/crsf_telemetry.h"
#include "drop/drop_detect.h"
#include "reaction_wheel/reaction_wheel.h"
#include "wheel_motor/wheel_motor.h"
#include "door/door.h"
#include "wings/wings.h"
#include "soft_pwm/soft_pwm.h"
#include "elevon/elevon.h"
#include "gps/gps.h"
#include "nav/nav.h"
#include "landing/landing_detect.h"
#include "indicator/indicator.h"
#include "mission/mission.h"
/* USER CODE END Includes */

/* USER CODE BEGIN PD */
#define IMU_PERIOD_MS    10u    /* 100 Hz sensor loop */
#define DEBUG_PERIOD_MS  200u
/* USER CODE END PD */

I2C_HandleTypeDef hi2c1;

TIM_HandleTypeDef htim1;
TIM_HandleTypeDef htim5;
TIM_HandleTypeDef htim11;

UART_HandleTypeDef huart2;
UART_HandleTypeDef huart6;

/* USER CODE BEGIN PV */
static Imu        imu;
static DropDetect drop;
static ReactionWheel rw;
static Mission    mission;
static Elevon     elevon;
static Gps        gps;
static Nav        nav;
static LandingDetect landing;
static CrsfTelemetryData tlm;
/* USER CODE END PV */

void SystemClock_Config(void);
static void MX_GPIO_Init(void);
static void MX_I2C1_Init(void);
static void MX_TIM1_Init(void);
static void MX_TIM5_Init(void);
static void MX_USART2_UART_Init(void);
static void MX_USART6_UART_Init(void);
static void MX_TIM11_Init(void);
/**
  * @brief  The application entry point.
  * @retval int
  */
int main(void)
{

  /* MCU Configuration--------------------------------------------------------*/

  /* Reset of all peripherals, Initializes the Flash interface and the Systick. */
  HAL_Init();

  /* Configure the system clock */
  SystemClock_Config();

  /* Initialize all configured peripherals */
  MX_GPIO_Init();
  MX_I2C1_Init();
  MX_TIM1_Init();
  MX_TIM5_Init();
  MX_USART2_UART_Init();
  MX_USART6_UART_Init();
  MX_TIM11_Init();
  /* USER CODE BEGIN 2 */
  uint8_t imuCount = imu_init(&imu, &hi2c1);
  imu_calibrate_gyro(&imu, 1000);      /* keep the board still for 1 s at boot */
  crsf_init(&huart6);
  drop_init(&drop);
  wheel_motor_init(&htim1);
  door_init(&htim5);
  wings_init(&htim5);
  soft_pwm_init(&htim5);     /* PC8/PC9 elevon servos, driven from TIM5 interrupts */
  elevon_init(&elevon);
  gps_init(&gps, &hi2c1);
  nav_init(&nav);
  landing_init(&landing);
  rw_init(&rw, wheel_motor_set);
  mission_init(&mission);

  char msg[192];
  int n = snprintf(msg, sizeof(msg), "boot: %u IMU(s) ok\r\n", imuCount);
  HAL_UART_Transmit(&huart2, (uint8_t *)msg, (uint16_t)n, 50);

  uint32_t nextImuMs = HAL_GetTick();
  uint32_t nextDebugMs = nextImuMs;
  /* USER CODE END 2 */

  /* Infinite loop */
  /* USER CODE BEGIN WHILE */
  while (1)
  {
    /* USER CODE END WHILE */

    /* USER CODE BEGIN 3 */
    uint32_t now = HAL_GetTick();
    gps_poll(&gps, now);
    crsf_telemetry_update(&tlm, now);
    indicator_update(drop_is_dropping(&drop), landing_is_landed(&landing), now);

    if ((int32_t)(now - nextImuMs) >= 0) {
      nextImuMs += IMU_PERIOD_MS;
      if (imu_update(&imu, now)) {
        drop_update(&drop, imu.accelMag, crsf_aux1_on(now), now);
        mission_update(&mission, &rw, drop_is_dropping(&drop),
                       imu.yawDeg, imu.fused.gz, now);
        rw_update(&rw, imu.yawDeg, IMU_PERIOD_MS * 0.001f);

        /* home = GPS position where the drop was detected */
        if (!drop_is_dropping(&drop)) nav_clear_home(&nav);
        else if (!nav.homeSet && gps_has_fix(&gps, now)) nav_set_home(&nav, gps.lat, gps.lon);
        nav_update(&nav, &gps, imu.fused.gz, IMU_PERIOD_MS * 0.001f, now);

        elevon_update(&elevon, imu.rollDeg, imu.pitchDeg, nav.rollTargetDeg,
                      IMU_PERIOD_MS * 0.001f, now, wings_are_ejected());
      }
      landing_update(&landing, drop_is_dropping(&drop), imu.accelMag,
                     imu.fused.gx, imu.fused.gy, imu.fused.gz,
                     gps_has_fix(&gps, now), gps.speedMs, now);

      /* snapshot for the CRSF telemetry downlink */
      tlm.rollDeg = imu.rollDeg;  tlm.pitchDeg = imu.pitchDeg;  tlm.yawDeg = imu.yawDeg;
      tlm.lat = gps.lat;  tlm.lon = gps.lon;  tlm.altM = gps.altM;
      tlm.speedMs = gps.speedMs;  tlm.courseDeg = gps.courseDeg;  tlm.satellites = gps.satellites;
      tlm.missionState = (uint8_t)mission.state;  tlm.missionName = mission_state_name(mission.state);
      tlm.elevonMode = (uint8_t)elevon.mode;      tlm.elevonName = elevon_mode_name(elevon.mode);
      tlm.flags = (uint8_t)((drop_is_dropping(&drop) ? CRSF_TLM_FLAG_DROPPING : 0) |
                            (landing_is_landed(&landing) ? CRSF_TLM_FLAG_LANDED : 0) |
                            (wings_are_ejected() ? CRSF_TLM_FLAG_WINGS : 0) |
                            (door_is_open() ? CRSF_TLM_FLAG_DOOR : 0) |
                            (gps_has_fix(&gps, now) ? CRSF_TLM_FLAG_GPS_FIX : 0) |
                            (crsf_aux1_on(now) ? CRSF_TLM_FLAG_AUX1 : 0) |
                            (imu.disagree ? CRSF_TLM_FLAG_IMU_DISAGREE : 0) |
                            (nav.active ? CRSF_TLM_FLAG_NAV_ACTIVE : 0));
      tlm.imuCount = imu_sensor_count(&imu);
      tlm.accelMag = imu.accelMag;  tlm.yawRateDps = imu.fused.gz;
      tlm.wheelCmd = rw.command;    tlm.rollTargetDeg = nav.rollTargetDeg;
      tlm.navDistM = nav.distM;     tlm.desiredCourseDeg = nav.desiredCourseDeg;
      tlm.leftUs = elevon.leftUs;   tlm.rightUs = elevon.rightUs;
    }

    if ((int32_t)(now - nextDebugMs) >= 0) {
      nextDebugMs += DEBUG_PERIOD_MS;
      int len = snprintf(msg, sizeof(msg),
                         "acc=%.2f yaw=%.1f imu=%u aux1=%u(%u) drop=%u mis=%s ev=%s r=%.0f p=%.0f gps=%u/%u nav=%u d=%.0f land=%u\r\n",
                         (double)imu.accelMag, (double)imu.yawDeg,
                         imu_sensor_count(&imu), crsf_aux1_on(now),
                         crsf_get_channel(CRSF_AUX1_CHANNEL), drop_is_dropping(&drop),
                         mission_state_name(mission.state), elevon_mode_name(elevon.mode),
                         (double)imu.rollDeg, (double)imu.pitchDeg,
                         gps_has_fix(&gps, now), gps.satellites, nav.active, (double)nav.distM, landing_is_landed(&landing));
      if (len > (int)sizeof(msg) - 1) len = (int)sizeof(msg) - 1;
      HAL_UART_Transmit(&huart2, (uint8_t *)msg, (uint16_t)len, 50);
    }
  }
  /* USER CODE END 3 */
}

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


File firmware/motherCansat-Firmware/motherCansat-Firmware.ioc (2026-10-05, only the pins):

Mcu.UserName=STM32F410RBTx
PA0-WKUP.Signal=S_TIM5_CH1
PA1.Signal=S_TIM5_CH2
PA10.Signal=S_TIM1_CH3
PA12.Signal=GPIO_Input
PA13.GPIO_Label=TMS
PA13.Signal=SYS_JTMS-SWDIO
PA14.GPIO_Label=TCK
PA14.Signal=SYS_JTCK-SWCLK
PA2.GPIO_Label=USART_TX
PA2.Signal=USART2_TX
PA3.GPIO_Label=USART_RX
PA3.Signal=USART2_RX
PA4.Signal=GPIO_Output
PA5.GPIO_Label=LD2 [Green Led]
PA5.Signal=GPIO_Output
PA8.Signal=S_TIM1_CH1
PA9.Signal=S_TIM1_CH2
PB12.Signal=GPIO_Output
PB13.Signal=GPIO_Output
PB14.Signal=GPIO_Output
PB15.Signal=GPIO_Output
PB3.GPIO_Label=SWO
PB3.Signal=SYS_JTDO-SWO
PB6.Signal=I2C1_SCL
PB7.Signal=I2C1_SDA
PC0.Signal=GPIO_Output
PC1.Signal=GPIO_Output
PC12.Signal=S_TIM11_CH1
PC13-ANTI_TAMP.GPIO_Label=B1 [Blue PushButton]
PC13-ANTI_TAMP.Signal=GPXTI13
PC14-OSC32_IN.Signal=RCC_OSC32_IN
PC15-OSC32_OUT.Signal=RCC_OSC32_OUT
PC2.Signal=GPIO_Output
PC3.Signal=GPIO_Output
PC4.Signal=GPIO_Output
PC5.Signal=GPIO_Analog
PC6.Signal=USART6_TX
PC7.Signal=USART6_RX
PC8.Signal=GPIO_Output
PC9.Signal=GPIO_Output

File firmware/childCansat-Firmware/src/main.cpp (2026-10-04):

#include <Arduino.h>
#include "comm/serial_cmd.h"
#include "core/state.h"
#include "mission/boot.h"
#include "mission/mission.h"
#include "sensors/sensors.h"
#include "ui/indicator.h"

void setup()
{
  bootSystem();
}

void loop()
{
  const uint32_t now = millis();

  if (state != STATE_LANDED) sampleSensors(now);

  switch (state)
  {
    case STATE_ARMED:   handleArmed(now);   break;
    case STATE_DESCENT: handleDescent(now); break;
    default: break;
  }

  updateLeds(now);
  beepUpdate(now);
  handleSerial();
}

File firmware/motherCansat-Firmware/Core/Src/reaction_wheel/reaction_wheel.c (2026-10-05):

#include "reaction_wheel.h"

float rw_wrap_deg(float deg)
{
    while (deg >= 180.0f) deg -= 360.0f;
    while (deg < -180.0f) deg += 360.0f;
    return deg;
}

static void apply(ReactionWheel *rw, float command)
{
    if (command > 1.0f) command = 1.0f;
    if (command < -1.0f) command = -1.0f;
    rw->command = command;
    if (rw->setMotor) rw->setMotor(command * rw->outputSign);
}

void rw_init(ReactionWheel *rw, RwMotorFn setMotor)
{
    rw->setMotor = setMotor;
    rw->mode = RW_OFF;
    rw->targetYawDeg = 0.0f;
    rw->outputSign = 1.0f;
    rw->command = 0.0f;
    rw->turnPower = RW_TURN_DEFAULT_POWER;
    rw->turnHandoverDeg = RW_TURN_DEFAULT_HANDOVER;
    rw->turnDoneDeg = RW_TURN_DEFAULT_DONE_DEG;
    rw->turnTimeoutMs = RW_TURN_DEFAULT_TIMEOUT_MS;
    rw->turnElapsedMs = 0;
    rw->turnBraking = 0;
    pid_init(&rw->pid, RW_DEFAULT_KP, RW_DEFAULT_KI, RW_DEFAULT_KD, -1.0f, 1.0f);
    pid_set_derivative_filter(&rw->pid, 0.3f);
    apply(rw, 0.0f);
}

void rw_set_gains(ReactionWheel *rw, float kp, float ki, float kd)
{
    pid_set_gains(&rw->pid, kp, ki, kd);
}

void rw_on(ReactionWheel *rw, float holdYawDeg)
{
    rw->targetYawDeg = holdYawDeg;
    pid_reset(&rw->pid);
    rw->mode = RW_HOLD;
}

void rw_off(ReactionWheel *rw)
{
    rw->mode = RW_OFF;
    pid_reset(&rw->pid);
    apply(rw, 0.0f);
}

void rw_set_target(ReactionWheel *rw, float targetYawDeg)
{
    rw->targetYawDeg = targetYawDeg;
}

uint8_t rw_is_on(const ReactionWheel *rw)
{
    return rw->mode != RW_OFF;
}

void rw_turn_to(ReactionWheel *rw, float targetYawDeg)
{
    rw->targetYawDeg = rw_wrap_deg(targetYawDeg);
    rw->turnElapsedMs = 0;
    rw->turnBraking = 0;
    pid_reset(&rw->pid);
    rw->mode = RW_TURN_FAST;
}

void rw_turn_by(ReactionWheel *rw, float currentYawDeg, float deltaDeg)
{
    rw_turn_to(rw, currentYawDeg + deltaDeg);
}

void rw_spin(ReactionWheel *rw, float command)
{
    rw->mode = RW_SPIN;
    apply(rw, command);
}

uint8_t rw_is_turning(const ReactionWheel *rw)
{
    return rw->mode == RW_TURN_FAST;
}

float rw_update(ReactionWheel *rw, float yawDeg, float dt)
{
    if (rw->mode == RW_OFF || rw->mode == RW_SPIN) return rw->command;

    float error = rw_wrap_deg(rw->targetYawDeg - yawDeg);
    float absErr = error < 0.0f ? -error : error;

    if (rw->mode == RW_TURN_FAST) {
        rw->turnElapsedMs += (uint32_t)(dt * 1000.0f);

        if (!rw->turnBraking) {
            if (absErr > rw->turnHandoverDeg && rw->turnElapsedMs < rw->turnTimeoutMs) {
                apply(rw, error > 0.0f ? rw->turnPower : -rw->turnPower);
                return rw->command;
            }
            rw->turnBraking = 1;        /* PID decelerates onto the target */
            pid_reset(&rw->pid);
        }
        if (absErr <= rw->turnDoneDeg || rw->turnElapsedMs >= rw->turnTimeoutMs * 2u) {
            rw->mode = RW_HOLD;         /* turn finished, keep holding */
        }
    }

    /* Work on the wrapped error so the +-180 boundary is continuous:
     * setpoint 0, measurement = -error (derivative then damps yaw rate). */
    float out = pid_update(&rw->pid, 0.0f, -error, dt);
    apply(rw, out);
    return rw->command;
}

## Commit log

2026-10-03 feat: Built simulator for verifying firmware and drew mother cansat PCB schematic
    Built simulator to verify firmware. Wrote firmware for simulator and found out all logics will perform well. But as real cansat will be worked with arduino pro mini 5v, the firmware will become littl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
    [control_core.kicad_sch, elrs.kicad_sch, kicad-pcb.dsn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]
2026-10-03 feat: add DHT11 temperatur/humidity library
    Built DHT11 library for child cansat.
2026-10-04 feat: add bmp280 library
    Built bmp280 library for child cansat. It calculates altitude using bmp280 sensor. So it gives various infos that is useful for cansat such as vertical speed, max/min altitude!
2026-10-04 feat: made entire flight logic for child cansat
    Built entire flight logic. Saves all datas in EEPROM. blue led blinks when it works well. red on when seonsors are broken. yellow on when EEPROM has flight data in it. yellow blinks when EEPROM is full.
    [boot.cpp, config.h, indicator.h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]
2026-10-04 feat: built gui tool's interface
    Made gui tool's interface for controlling in ground. And made gave function for getting sensor data from cansat's EEPROM!
2026-10-04 feat: mother cansat cubemx done
    Done cubemx pin&clock configuration in stm32 cubemx. for NUCLEO-f410RB!
2026-10-05 feat: built function for pid loop
    Built function for pid loop that calculates pid for reaction wheel!
2026-10-05 feat: built crsf & imu library
    built imu library for mpu6050 and icm-42688 and combine them in one data. And made it to detect dropping using imus. And made crsf library.
2026-10-05 feat: built gui tool for controlling
    built gui ground controlling system.
2026-10-05 chore: delete simulator that is not needed!
    As this simulator is currently not needed, deleted it!
2026-10-07 chore: little 3d models and code fix
    [child-cansat-body.3mf, child-cansat-cover.3mf, control_core.kicad_sch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]
2026-10-27 feat: add KAIST ground station with flight and wind-field web UI
2026-10-28 feat: add record button, bluetooth connect and link quality indicator
2026-11-02 docs: describe the KAIST kit ground station in the readme
2026-11-02 feat: add windows launcher for the kaist ground station
2026-11-03 feat: receive on a dedicated loop, accept camera settings ack and add parachute servo buttons

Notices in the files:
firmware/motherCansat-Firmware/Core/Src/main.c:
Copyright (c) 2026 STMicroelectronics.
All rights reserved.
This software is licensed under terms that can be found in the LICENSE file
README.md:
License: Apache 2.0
